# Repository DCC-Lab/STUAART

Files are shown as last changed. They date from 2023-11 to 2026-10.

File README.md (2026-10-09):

# STUAART

Repository of the STUAART project. 
Authors of this README : Valérie Pineau Noël, Nathan Bérubé and Daniel C. Côté (DCC/M-lab, CERVO brain research center, Université Laval)

## Overview

STUAART is an automated weighing system for mice that tracks individual weights over weeks. Each cage holds three independent scales ; each scale is a load cell (Wheatstone bridge) read by an HX711 24-bit amplifier connected via a 2-pin protocol (DOUT, SCK) to a DFRobot FireBeetle ESP32 V1 microcontroller. The microcontroller logs every measurement to a microSD card and exposes a small HTTP server so a host can pull today's CSV over Wi-Fi.

## Repository layout

| Folder | What's there |
|---|---|
| `Arduino/` | Custom libraries and scripts to run the STUAART. |
| `KiCAD/` | PCB schematic and design mde on KiCAD (version 10.0.7). |
| `CAD/` | Mechanical 3D files for the scale platforms. Print the top platform with high infill density to keep stiffness and reduce creep. |
| `FlaskServer/` | Python script used to catch the data and save on a local NAS. |
| `Notebooks/` | Notebooks that users can run in Google Colaboratory for data post-processing. |

## Getting started with the firmware

1. Install Arduino IDE 2.x or `arduino-cli`.
2. Add the Espressif boards URL in Preferences and install the `esp32` core (board package). 
3. Copy and save files in folder `Arduino` on your computer. 
4. Copy and save the Python script in `FlaskServer` in your local NAS and run it. 
5. If you are using a new Firebeetle ESP-32 board, run `Arduino/FormatSPIFFS/FormatSPIFFS.ino` (prevent error `SPIFFS Mount Failed`). Otherwise, go to the next step. 
6. Open `Arduino/STUAART/STUAART.ino`.
7. Download third-party libraries in the Arduino IDE. See section *Required third-party libraries*.
8. In the Arduino IDE, pick board `FireBeetle-ESP32` (`esp32:esp32:firebeetle32`) in  Tools -> Port, pick the USB serial port, then Verify and Upload.

## Required third-party libraries

Install these via Arduino IDE Library Manager (Sketch -> Include Library -> Manage Libraries):

| Library | Author | Tested version |
|---|---|---|
| HX711 | Bogdan Necula (bogde) | 0.7.5 |
| RTClib | Adafruit | 2.1.4 |
| ArduinoJson | Benoit Blanchon | 7.0.4 |

## A minimal load cell read

```cpp
#include "LoadCell.h"
#include "LoadCellController.h"

LoadCell loadcell;
LoadCellController controller;

void setup() {
  Serial.begin(115200);
  controller.add_loadcell(loadcell);
  controller.easy_start_with_params(
      1,        // loadcell number
      27,       // DOUT pin (avoid GPIO 6-11, those are the flash bus)
      17,       // SCK pin
      true,     // calibrate offset
      true,     // calibrate scale
      false,    // read offset from memory
      false,    // read scale from memory
      true,     // save offset to memory
      true,     // save scale to memory
      0,        // manual tare offset (0 = not specified)
      0,        // manual scale coeff (0 = not specified)
      128       // gain, do not change
  );
}

void loop() {
  controller.wait_ready_timeout(1, 1000);
  float reading = controller.get_weight(1);
  Serial.println(reading);
}
```

## Mass time series analysis

Each step of the post-processing analysis can be performed using notebooks run via Google Colaboratory. To begin, the raw mass time series must be uploaded to the user's personal Google Drive. We also recommend that users save a personal copy of each notebook to their own Google Drive by clicking on *File > Save a copy in Drive* once opened via the links below. Users are free to modify their own versions of the notebooks as desired. 

1. **Remove buffer flush indicators from the raw mass time series** : String such as "--, --, --, -- \n" are saved in the raw data to indicate the moments when the buffer flushed its contents onto the SD card. This data can be used to evaluate the time it takes to flush all data and how many times the buffer flushes the data over a given period. For further analysis, these indicators nust be removed. You can do this using this notebook :


2. **Correct for baseline shift and remove outliers** : This step is the most computationally intensive. Longitudinal mass time series are affected by mechanical and thermal drifts that alter the value of the initial tare and shift the measured mass by multiple grams, which must be corrected to ensure accuracte evaluation. Additionally, transient spikes can occur and should be filtered out. Users can choose whether to remove outliers and select which baseline correction algorithm best suits their data. Four baseline correction algorithms are provided : density-based spatial clustering of applications with noise (DBSCAN), kernel-density estimation (KDE), Gaussian mixture model (GMM) and a custom rolling-mean filtering. As presented in the main manuscript, the authors achieved optimal results with DBSCAN, while the custom rolling-mean filtering performs well for more stable data sets. We also provide a graphical user interface (GUI) for manual baseline fine-tuning and quick data visualization. We suggest testing different algorithms and using the notebook *Compute_metrics.ipnyb* to evaluate quantitatively the accuracy and precision of the baseline-corrected mass compared to ground-truth mass measurements. If ground-truth data was not acquired, a simple visual inspection of the baseline-corrected mass time series can guide algorithm selection. More information is available in the supplementary information document and within the notebook :


3. **Display mass time series and compute mass per time bin** : After baseline correction and outlier removal, the users can display the mass time series for visual evaluation. The data can be displayed per scale, for the overall measured mass of the system (summed mass time series per timepoint) and by the relative mass change (where the mass at time = 0 hour is 0%). The users can also obtain the mass per time bin. 


4. **Compute metrics** : Quantitative evaluation of the mass compared to ground-truth measurements can be obtained via this notebook : 


5. **Evaluate location, grid-hanging and active state behaviors** : Three additional notebooks are provided to identify and evaluate the spatial occupancy of each scale, the grid-hanging behavior and the active VS inactive states over time. 
   - 
   - 
   - 

## Error management 

- `Unable to verify flash chip connection` : the default upload speed of 921600 baud is too fast for the CH340 USB-serial chip on the FireBeetle. Set 115200. 

- `SPIFFS Mount Failed` : Run the script in `Arduino/FormatSPIFFS/FormatSPIFFS.ino`. 

- The "GPIO 9 = flash" issue on cell 1 is the root cause of corrupted readings (raw == 0xFFFFFF returned as -160.68 g). A defensive software patch in `LoadCell.cpp` rejects this signature, but the long-term fix is to reroute that DOUT to GPIO 25 or 26 (silkscreen D2 or D3).

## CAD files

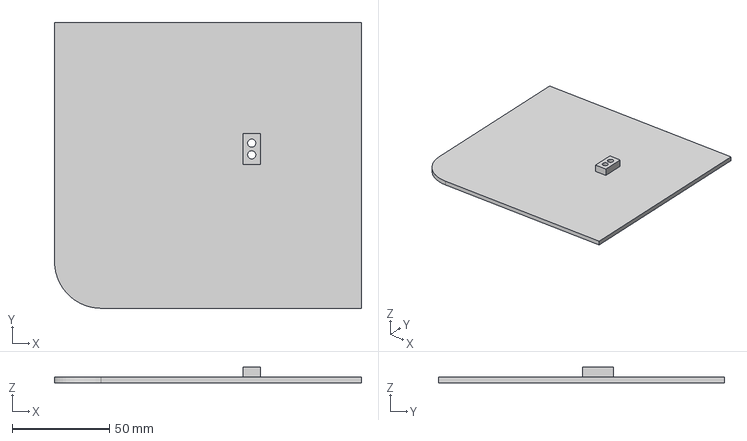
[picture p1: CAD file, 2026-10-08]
CAD/TopRight.step
158.0 x 147.0 x 8.00 mm

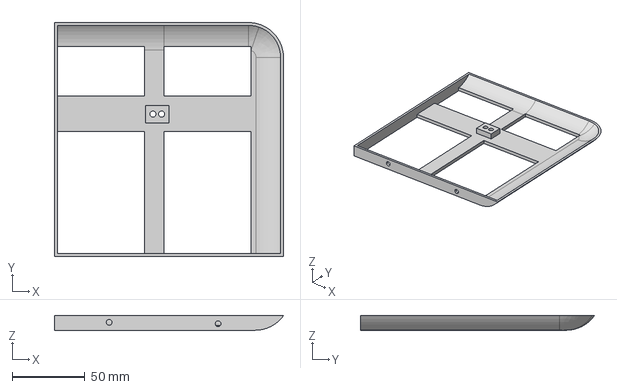
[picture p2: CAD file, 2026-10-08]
CAD/BottomRight.step
157.6 x 161.0 x 10.0 mm

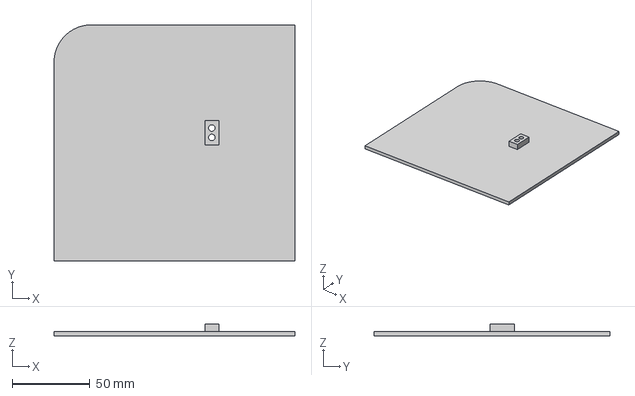
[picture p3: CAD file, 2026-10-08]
CAD/TopLeft.step
155.0 x 152.0 x 8.00 mm

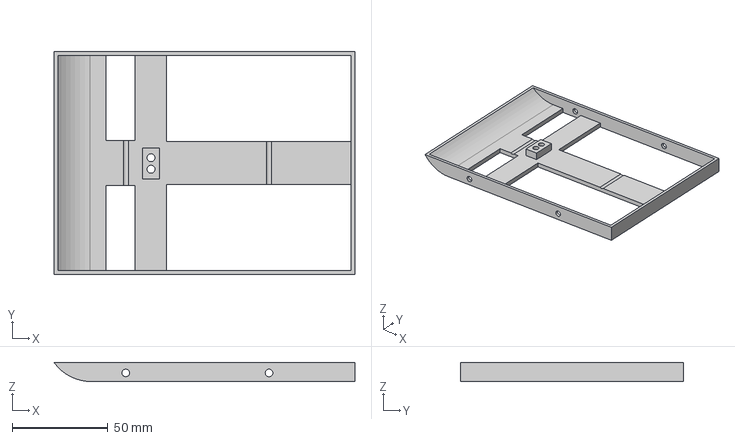
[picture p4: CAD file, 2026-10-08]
CAD/BottomMiddle.step
157.6 x 116.5 x 10.0 mm

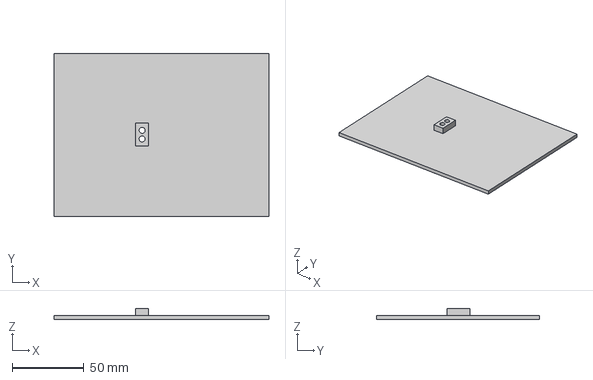
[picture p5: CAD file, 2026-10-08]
CAD/TopMiddle.step
150.0 x 114.0 x 8.00 mm

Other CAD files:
CAD/BottomLeft.step

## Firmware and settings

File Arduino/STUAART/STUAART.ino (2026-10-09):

#include "LoadCell.h"
#include "LoadCellController.h"
#include <WiFi.h>
#include <SD.h>
#include <SPI.h>
#include <Wire.h>
#include "RTClib.h"
#include <time.h>
#include <HTTPClient.h>
#include <ArduinoJson.h>  // Install via Library Manager
#include <esp_system.h>

RTC_PCF8523 rtc; // Create an RTC object for the PCF8523

LoadCell loadCell1;
LoadCell loadCell2;
LoadCell loadCell3;
LoadCellController controller;

const int pinLED1 = 10;
const int pinLED2 = 2;
const int pinLED3 = 14;
const int pinLED4 = 15;

const int MODE_PIN = 13; //Switch pin allowing to put in setup mode.

File myFile;           // initialize the file
const int SS_PIN = 5; // seule pin de carte SD à spécifier

// Compiled-in defaults. Overridden at boot by /wifi.txt on SPIFFS if
// present. Use the `wifi set <ssid> <password>` serial command to
// change them at runtime ; the new values are persisted to SPIFFS so
// they survive reboots.
char ssid[64]     = "INTERNET-EQUIPEMENTS";
char password[64] = "zfrnxbg7";
WiFiServer server(80);             // créer un serveur qui écoute les clients qui veulent s'y connecter

const char *REFRESH_CODE = "refresh"; // must be the same as in the python code, otherwise they won't be able to recognize one another

unsigned long saveTimestamp = 0;
const int SAVE_DATA_INTERVAL = 0; 

unsigned long reconnectTimestamp = 0;
const int RECONNECT_WIFI_INTERVAL = 3600000;
const unsigned long WIFI_CONNECT_TIMEOUT_MS = 15000;
bool wifiConnected = false;
bool sdInitialized = false;
bool webServerStarted = false;     // set when server.begin() succeeds
bool streamOn = false;                  // CSV stream to Serial : OFF by default
const size_t CMD_BUF_SIZE = 64;
char cmdBuf[CMD_BUF_SIZE];              // accumulates one line of user input
size_t cmdLen = 0;
char pendingCmd[CMD_BUF_SIZE] = "";     // command awaiting y/n confirmation

// Ring buffer of the last BUFFER_SIZE CSV lines, kept in RAM
// independently of the SD card. The ring overwrites the oldest line
// when full, so it always reflects the most recent ~12 s of data
// (1000 samples / 80 Hz). Used both for batched SD writes and to back
// the HTTP `/recent` endpoint.
const int BUFFER_SIZE = 1000;
const int LINE_LENGTH = 64;        // max line for 7-column 7-field CSV
char buffer[BUFFER_SIZE][LINE_LENGTH];
int  head = 0;                     // next slot to write
int  tail = 0;                     // oldest slot (== head when full)
bool bufferFull = false;
unsigned long ringWrites    = 0;   // total adds since boot
unsigned long ringSdFlushed = 0;   // number of writes already on SD
const int SD_FLUSH_EVERY = 500;    // flush every ~6 s at 80 Hz

//Buffer chars for saving files
static char today[16];
static char yesterday[16];

char currentTime[13];

/**
 * @brief Try to connect to WiFi using the hardcoded SSID and PASSWORD.
 *
 * Retries every 500 ms until the chip reports `WL_CONNECTED` or the
 * configured `WIFI_CONNECT_TIMEOUT_MS` (15 s) elapses, whichever comes
 * first. On success, sets the global `wifiConnected = true`, starts the
 * HTTP `server`, and blinks `pinLED2` three times. On timeout, sets
 * `wifiConnected = false` and continues without network ; the firmware
 * keeps logging to SD and (if enabled) Serial.
 *
 * Called once from @ref setup and again on a 1-hour interval from
 * @ref loop, so a transient outage recovers automatically.
 */
void logResetReasonToSD() {
  esp_reset_reason_t reason = esp_reset_reason();
  String reasonStr = "";

  // Translate the ESP32 hardware flag into a clear text message
  switch (reason) {
    case ESP_RST_POWERON:  reasonStr = "POWER-ON (Normal cold boot)"; break;
    case ESP_RST_BROWNOUT: reasonStr = "BROWNOUT DETECTED! (Voltage dipped too low)"; break;
    case ESP_RST_SW:       reasonStr = "SOFTWARE RESET (Rebooted via code)"; break;
    case ESP_RST_PANIC:    reasonStr = "CRASH / PANIC (Exception or code error)"; break;
    case ESP_RST_INT_WDT:  reasonStr = "WATCHDOG TIMEOUT (Interrupt WDT)"; break;
    case ESP_RST_TASK_WDT: reasonStr = "WATCHDOG TIMEOUT (Task WDT)"; break;
    case ESP_RST_DEEPSLEEP:reasonStr = "DEEP SLEEP WAKEUP"; break;
    case ESP_RST_EXT:      reasonStr = "EXTERNAL RESET (Reset button pressed)"; break;
    default:               reasonStr = "UNKNOWN RESET REASON"; break;
  }

  // Open a system log file on the SD card (or append to your main CSV)
  File logFile = SD.open("/system_log.txt", FILE_APPEND);
  if (logFile) {
    logFile.print("[BOOT EVENT] Reason: ");
    logFile.println(reasonStr);
    logFile.close();
  }
}


void connectToWifi()
{
  // Disconnect any previous attempt and clear the AP config so a fresh
  // begin() does not collide with an in-flight state machine. Without
  // this, calling connectToWifi a second time (e.g. after a `wifi set`
  // command) triggers ESP-IDF :
  //     E (xxxxx) wifi:sta is connecting, cannot set config
  // even though the previous attempt has already timed out.
  WiFi.disconnect(false, true);   // (wifioff=false, eraseap=true)
  WiFi.mode(WIFI_STA);
  delay(100);

  Serial.print("Connecting to ");
  Serial.println(ssid);
  WiFi.begin(ssid, password);
  unsigned long start = millis();
  while (WiFi.status() != WL_CONNECTED && (millis() - start) < WIFI_CONNECT_TIMEOUT_MS)
  {
    delay(500);
    Serial.print(".");
  }
  Serial.println("");
  if (WiFi.status() == WL_CONNECTED) {
    wifiConnected = true;
    Serial.println("WiFi connected.");
    Serial.println("IP address: ");
    Serial.println(WiFi.localIP());
    server.begin();
    webServerStarted = true;
    for (int i = 0; i < 3; i++) {
      digitalWrite(pinLED2, HIGH); delay(100);
      digitalWrite(pinLED2, LOW);  delay(100);
    }
  } else {
    wifiConnected = false;
    Serial.println("WiFi unavailable, continuing without network.");
  }
}


/**
 * @brief Load WiFi credentials from `/wifi.txt` on SPIFFS into the
 * global `ssid` and `password` buffers.
 *
 * File format : two lines, SSID then PASSWORD, each terminated by a
 * newline. If the file is absent, malformed, or SPIFFS itself fails
 * to mount, the compiled-in defaults are kept untouched. Called once
 * from setup() before the first connectToWifi() attempt.
 */
void loadWifiConfig() {
  if (!SPIFFS.begin(true)) return;
  File f = SPIFFS.open("/wifi.txt", FILE_READ);
  if (!f) return;
  String s = f.readStringUntil('\n'); s.trim();
  String p = f.readStringUntil('\n'); p.trim();
  f.close();
  if (s.length() > 0 && s.length() < sizeof(ssid))     strcpy(ssid, s.c_str());
  if (p.length() > 0 && p.length() < sizeof(password)) strcpy(password, p.c_str());
  Serial.print(F("Loaded WiFi SSID from SPIFFS: "));
  Serial.println(ssid);
}

/**
 * @brief Persist the current `ssid` and `password` buffers to
 * `/wifi.txt` on SPIFFS so they survive a reboot.
 *
 * @return true if the file was written successfully.
 */
bool saveWifiConfig() {
  if (!SPIFFS.begin(true)) return false;
  File f = SPIFFS.open("/wifi.txt", FILE_WRITE);
  if (!f) return false;
  f.println(ssid);
  f.println(password);
  f.close();
  return true;
}

/**
 * @brief Print the current WiFi SSID on Serial. The password is NEVER
 * printed (anyone with access to the bench Serial port could read it).
 */
void printWifiConfig() {
  Serial.print(F("SSID     : ")); Serial.println(ssid);
  Serial.print(F("password : (not shown ; "));
  Serial.print(strlen(password));
  Serial.println(F(" chars stored)"));
  Serial.print(F("connected: "));
  Serial.println(wifiConnected ? "yes" : "no");
}

/**
 * @brief Fetch the current local time from timeapi.io over HTTPS.
 *
 * Issues a GET to `https://timeapi.io/api/Time/current/zone?timeZone=America/Toronto`,
 * parses the JSON response with ArduinoJson, and reads the `datetime`
 * field. Currently the result is not pushed to the RTC (the JSON is
 * extracted but the assignment is commented out) ; this function is a
 * stub for future synchronization.
 *
 * Requires WiFi to be connected. Logs an error otherwise.
 */
void getTimeHTTP() {
  if ((WiFi.status() == WL_CONNECTED)) {
    HTTPClient http;
    // Make request to worldtimeapi.org for your timezone (or "api/ip" for auto-detect)
    http.begin("https://timeapi.io/api/Time/current/zone?timeZone=America/Toronto");
    int httpCode = http.GET();

    if (httpCode > 0) { // Check for the returning code
      String payload = http.getString();
      // Serial.println("HTTP Response:");
      // Serial.println(payload);
      // Parse JSON
      DynamicJsonDocument doc(4096);
      DeserializationError error = deserializeJson(doc, payload);
      if (!error) {
        const char* datetime;
        datetime = doc["datetime"];  // e.g., "2025-10-02T17:15:30.123456+00:00"
        // Serial.print("Current time: ");
        // Serial.println(datetime);
      } else {
        Serial.print("JSON parse error: ");
        Serial.println(error.c_str());
      }
    } else {
      Serial.print("HTTP GET failed, code: ");
      Serial.println(httpCode);
    }
    http.end();
  } else {
    Serial.println("WiFi not connected");
  }
}



/**
 * @brief Initialize the PCF8523 real-time clock and seed it with the
 * compile-time date and time.
 *
 * Halts the firmware in an infinite loop if `rtc.begin()` fails (no
 * RTC found on the I2C bus). On success, calls `rtc.adjust()` with
 * the `__DATE__`/`__TIME__` macros so the clock is at least roughly
 * correct after a flash, and `rtc.start()` to clear any STOP bit.
 *
 * The compile-time seed is a coarse fallback ; for accurate time use
 * the `time YYYY-MM-DD HH:MM:SS` serial command after boot.
 */
void startRealTimeClock(){
  // Wait for serial port to connect. Needed for native USB port only
  #ifndef ESP8266
    while (!Serial); 
  #endif
  if (! rtc.begin()) { // Attempt to initialize the RTC
    Serial.println("Couldn't find RTC");
    Serial.flush();
    while (1) delay(10);
  }

  else {
    Serial.println("RTC setup succeeded");
  }
  if (digitalRead(MODE_PIN) == HIGH) { // during manual calibration mode
    rtc.adjust(DateTime(F(__DATE__), F(__TIME__))); 
  }
  rtc.start(); // Ensure the RTC is running (clears the STOP bit if necessary)
}


/**
 * @brief Format today's date as a CSV filename in the global `today[]`
 * buffer, e.g. `/2026.05.06.csv`.
 *
 * Reads the current time from the PCF8523 RTC and writes the formatted
 * string into `today[]` via `snprintf`. Used by @ref saveData to pick
 * the destination file on the SD card.
 */
void getTodaysDate(){
  DateTime now = rtc.now(); // Get the current date and time from the RTC
  int year = now.year();
  int month = now.month();
  int day = now.day();

  snprintf(today, sizeof(today), "/%04d.%02d.%02d.csv", year, month, day);
} 


/**
 * @brief Format yesterday's date as a CSV filename in the global
 * `today[]` buffer (sic ; the function reuses the same buffer).
 *
 * @warning Naive implementation : subtracts 1 from `now.day()` without
 * handling month / year roll-over. Fails on the first of any month.
 */
void getYesterdaysDate(){
  DateTime now = rtc.now(); // Get the current date and time from the RTC
  int year = now.year();
  int month = now.month();
  int day = now.day() - 1;

  snprintf(today, sizeof(today), "/%04d.%02d.%02d.csv", year, month, day);
}


/*
Gets current time from the real-time clock.
*/
void getCurrentTime(){
  DateTime now = rtc.now(); // Get current date and time from the RTC
  int hours = now.hour();
  int minutes = now.minute();
  int seconds = now.second();

  int milliseconds = millis() % 1000;

  snprintf(currentTime, sizeof(currentTime), "%02d:%02d:%02d.%03d", hours, minutes, seconds, milliseconds);
}


/*
Writes a file in the SD card at the specified path. Puts in the specified message.
Writes in the serial consol error if it doesn't succeed.
*/
void writeFile(const char *path, const char *message, const char *mode){
  if (bufferFull == false){
    addToBuffer(message);
  }
  else
    {
      while (!Serial)
    {
      ; // wait for serial port to connect. Needed for native USB port only
    }
      // open the file. note that only one file can be open at a time,
    myFile = SD.open(path, mode);
    // if the file opened okay, write to it:
    if (myFile)
      {
      // close the file:
      flushBufferToSD();
      myFile.print(message);
      myFile.close();
      digitalWrite(pinLED1, HIGH);
      delay(50);
      digitalWrite(pinLED1, LOW);
      }
    else
      {
      // if the file didn't open, print an error:
      Serial.println("error opening file");
      }
}
}

/**
 * @brief Create or truncate a file on the SD card and write a single
 * line to it.
 *
 * Used by @ref writeFileHeader to drop the CSV header at the top of a
 * new daily file. No-op if `sdInitialized` is `false`.
 *
 * @param path Destination filename on the SD card.
 * @param message Null-terminated text written via `myFile.println()`
 * (a `\n` is appended automatically).
 * @param mode Typically `FILE_WRITE` (truncates).
 */
void createFile(const char *path, const char *message, const char *mode){
  if (!sdInitialized) return;
  myFile = SD.open(path, mode);
  if (myFile) {
    myFile.println(message);
    myFile.close();
  } else {
    Serial.println("error opening file");
  }
}


/**
 * @brief Append a CSV line to the in-RAM ring buffer with overwrite-oldest
 * semantics.
 *
 * Copies up to `LINE_LENGTH - 1` characters from `message` into
 * `buffer[head]`, advances head modulo BUFFER_SIZE, and once the ring
 * is full keeps `tail` glued to head so the oldest line is dropped on
 * each new write. The ring therefore always reflects the most recent
 * BUFFER_SIZE samples regardless of SD availability.
 *
 * @param message Null-terminated CSV line (truncated if longer than
 * `LINE_LENGTH - 1` bytes).
 */
void addToBuffer(const char *message) {
  strncpy(buffer[head], message, LINE_LENGTH - 1);
  buffer[head][LINE_LENGTH - 1] = '\0';
  head = (head + 1) % BUFFER_SIZE;
  if (bufferFull) {
    tail = (tail + 1) % BUFFER_SIZE;     // drop oldest
  } else if (head == tail) {
    bufferFull = true;                   // first wrap : ring is now full
  }
  ringWrites++;
}


/**
 * @brief Stream the ring buffer contents (oldest to newest) to a Print
 * target.
 *
 * Used both for SD flushing and for the HTTP `/recent` endpoint. The
 * ring itself is unchanged after the call : the data remains available
 * for further consumers.
 *
 * @param out Print target (File, WiFiClient, HardwareSerial, etc.).
 */
void streamRingTo(Print &out) {
  int n     = bufferFull ? BUFFER_SIZE : head;
  int start = bufferFull ? head : 0;     // when not full, oldest is slot 0
  for (int i = 0; i < n; i++) {
    out.print(buffer[(start + i) % BUFFER_SIZE]);
  }
}


void flushBufferToSD(){
  while (head != tail || bufferFull) {
    myFile.print(buffer[tail]);
    tail = (tail + 1) % BUFFER_SIZE;
    bufferFull = false;
  }
  myFile.print("--, --, --, -- \n");
}



/**
 * @brief Write the 7-column CSV header at the top of a new daily file.
 *
 * Header :
 * `time (ms), reading 1, reading 2, reading 3, raw 1, raw 2, raw 3`
 *
 * The `reading` wording is preserved so existing post-processing scripts
 * that match on those names keep working ; the three `raw` columns are
 * the new signed 24-bit HX711 counts.
 *
 * @param file_name Destination CSV path on the SD card.
 */
void writeFileHeader(char *file_name) {
  createFile(file_name, "time [HH:MM:SS.MS], reading 1, reading 2, reading 3", FILE_WRITE);
}


/**
 * @brief Sample the 3 load cells once and persist the row.
 *
 * Reads the raw 24-bit count from each cell via `read_raw_average()`
 * and converts each one to grams via `mass_from_raw()`, so the weight
 * and raw on the same line come from the *same* HX711 conversion (no
 * double read). Builds a 7-field CSV line :
 *
 * `time(ms), w1, w2, w3, raw1, raw2, raw3\n`
 *
 * If the SD card is initialised, the line is appended to today's file
 * (creating it with a header if needed). If `streamOn` is true, the
 * same line is mirrored on Serial.
 *
 * Called every iteration of @ref loop ; throughput is bounded by the
 * HX711 conversion rate (~80 Hz on STUAART hardware).
 */
void saveData()
{
  // Read raws once and derive weights from them, so the two values on
  // the same line come from the SAME HX711 conversion (no double read).
  long raw1 = controller.read_raw_average(1);
  long raw2 = controller.read_raw_average(2);
  long raw3 = controller.read_raw_average(3);
  float weight1 = controller.mass_from_raw(1, raw1);
  float weight2 = controller.mass_from_raw(2, raw2);
  float weight3 = controller.mass_from_raw(3, raw3);

  getCurrentTime();

  String fileLine = "";
  fileLine += String(currentTime) + "," + weight1 + "," + weight2 + "," + weight3 + "\n";

  // Always feed the ring : it backs the HTTP /recent endpoint and the
  // SD flush below. Independent of sdInitialized.
  addToBuffer(fileLine.c_str());

  // Periodic SD flush : every SD_FLUSH_EVERY samples, append the most
  // recent unflushed lines to today's file. Doing it in batches avoids
  // opening / closing SD on every sample.
  if (sdInitialized && (ringWrites - ringSdFlushed) >= (unsigned long) SD_FLUSH_EVERY) {
    getTodaysDate();
    if (!SD.exists(today)) writeFileHeader(today);

    myFile = SD.open(today, FILE_APPEND);
    if (myFile) {
      int toWrite = (int) (ringWrites - ringSdFlushed);
      if (toWrite > BUFFER_SIZE) toWrite = BUFFER_SIZE;   // cap to ring depth
      int start = (head - toWrite + BUFFER_SIZE) % BUFFER_SIZE;
      for (int i = 0; i < toWrite; i++) {
        myFile.print(buffer[(start + i) % BUFFER_SIZE]);
      }
      myFile.close();
      ringSdFlushed = ringWrites;
      digitalWrite(pinLED1, HIGH); delay(100); digitalWrite(pinLED1, LOW);
    } else {
      Serial.println(F("SD append failed (will retry on next flush)"));
    }
  }

  if (streamOn) {
    Serial.print(fileLine);
  }
}
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
void loop() {
  unsigned long currentMillis = millis();

  // Serial command interface
  processSerialInput();

  // Save data on SD card
  if (abs((long)(currentMillis - saveTimestamp)) >= SAVE_DATA_INTERVAL) {
    saveTimestamp = currentMillis;
    saveData();
  }

  // Reconnect WiFi is disconnected 
  if (abs((long)(currentMillis - reconnectTimestamp)) >= RECONNECT_WIFI_INTERVAL) {
    reconnectTimestamp = currentMillis;
    connectToWifi();
  }

  if (millis() - lastUploadTime > 300000) {
    getTodaysDate();
    pushToServer(today);
    lastUploadTime = millis();
  }
}

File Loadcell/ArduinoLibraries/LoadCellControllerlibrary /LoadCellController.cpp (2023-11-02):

#include "LoadCellController.h"

LoadCellController::LoadCellController()
{
}

void LoadCellController::add_loadcell(LoadCell &loadcell)
{
    loadcells[n_loadcell] = &loadcell;
    n_loadcell++;
}

void LoadCellController::easy_start_with_params(
    byte loadcell_num,
    byte dout,
    byte pd_sck,
    bool calibrate_offset,
    bool calibrate_scale,
    bool read_offset_persistent_memory,
    bool read_scale_persistent_memory,
    bool save_offset_persistent_memory,
    bool save_scale_persistent_memory,
    float tare_offset,
    float scale_coeff,
    byte gain)
    {
    easy_handle_exceptions(
        loadcell_num,
        calibrate_offset,
        calibrate_scale,
        read_offset_persistent_memory,
        read_scale_persistent_memory,
        save_offset_persistent_memory,
        save_scale_persistent_memory,
        tare_offset,
        scale_coeff);

    LoadCell *loadcell_ptr = loadcells[loadcell_num - 1];

    loadcell_ptr->begin(dout, pd_sck, gain);

    loadcell_ptr->set_offset(tare_offset);
    loadcell_ptr->set_scale(scale_coeff);

    easy_read_from_persistent_memory_with_params(
        loadcell_num,
        read_offset_persistent_memory,
        read_scale_persistent_memory);

    easy_calibration_with_params(
        loadcell_num,
        calibrate_offset,
        calibrate_scale); // set offset and scale with calibration or with value

    easy_save_to_persistent_memory_with_params(
        loadcell_num,
        save_offset_persistent_memory,
        save_scale_persistent_memory); // set offset and scale with calibration or with value
    Serial.println(F("---------***---------"));
}

void LoadCellController::easy_read_from_persistent_memory_with_params(
    byte loadcell_num,
    bool read_offset,
    bool read_scale)
{
    LoadCell *loadcell_ptr = loadcells[loadcell_num - 1];

    if (read_offset && read_scale)
    {
        loadcell_ptr->set_offset(read_offset_from_persistent_memory(loadcell_num));
        loadcell_ptr->set_scale(read_scale_coeff_from_persistent_memory(loadcell_num));
        Serial.println(F("Offset and scale coefficient read from memory"));
        Serial.print(F("Offset: "));
        Serial.println(loadcell_ptr->get_offset());
        Serial.print(F("Scale coefficient: "));
        Serial.println(loadcell_ptr->get_scale());
        Serial.println(F("---------***---------"));
    }
    else if (read_offset && !read_scale)
    {
        loadcell_ptr->set_offset(read_offset_from_persistent_memory(loadcell_num));
        Serial.println(F("---------***---------"));
        Serial.println(F("Offset read from memory"));
        Serial.print(F("Offset: "));
        Serial.println(loadcell_ptr->get_offset());
    }
    else if (!read_offset && read_scale)
    {
        loadcell_ptr->set_scale(read_scale_coeff_from_persistent_memory(loadcell_num));
        Serial.println(F("---------***---------"));
        Serial.println(F("Scale coefficient read from memory"));
        Serial.print(F("Scale coefficient: "));
        Serial.println(loadcell_ptr->get_scale());
    }
}

void LoadCellController::easy_calibration_with_params(
    byte loadcell_num,
    bool calibrate_offset,
    bool calibrate_scale)
{
    LoadCell *loadcell_ptr = loadcells[loadcell_num - 1];
    if (calibrate_offset && calibrate_scale)
    {
        calibrate_both_params(loadcell_num); // set offset and scale
        Serial.print(F("Offset: "));
        Serial.println(loadcell_ptr->get_offset());
        Serial.print(F("Scale coefficient: "));
        Serial.println(loadcell_ptr->get_scale());
    }
    else if (calibrate_offset && !calibrate_scale)
    {
        calibrate_tare_offset(loadcell_num); // set offset
    }
    else if (!calibrate_offset && calibrate_scale)
    {
        calibrate_scale_coeff(loadcell_num); // set scale
    }
}

void LoadCellController::easy_save_to_persistent_memory_with_params(
    byte loadcell_num,
    bool save_offset,
    bool save_scale)
{
    LoadCell *loadcell_ptr = loadcells[loadcell_num - 1];

    if (save_offset && save_scale)
    {
        save_offset_to_persistent_memory(loadcell_num);
        save_scale_coeff_to_persistent_memory(loadcell_num);
        Serial.println(F("---------***---------"));
        Serial.println(F("Offset and scale coefficient saved to persistent memory."));
        Serial.print(F("Offset: "));
        Serial.println(loadcell_ptr->get_offset());
        Serial.print(F("Scale coefficient: "));
        Serial.println(loadcell_ptr->get_scale());
    }
    else if (save_offset && !save_scale)
    {
        save_offset_to_persistent_memory(loadcell_num);
        Serial.println(F("---------***---------"));
        Serial.println(F("Offset saved to persistent memory."));
        Serial.print(F("Offset: "));
        Serial.println(loadcell_ptr->get_offset());
    }
    else if (!save_offset && save_scale)
    {
        save_scale_coeff_to_persistent_memory(loadcell_num);
        Serial.println(F("---------***---------"));
        Serial.println(F("Scale coefficient saved to persistent memory."));
        Serial.print(F("Scale coefficient: "));
        Serial.println(loadcell_ptr->get_scale());
    }
}

void LoadCellController::easy_start_with_questions(
    byte loadcell_num,
    byte dout,
    byte pd_sck,
    byte gain)
{
    // not implemented
}
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

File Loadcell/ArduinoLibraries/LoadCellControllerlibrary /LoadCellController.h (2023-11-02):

/**
 * @file LoadCellController.h
 *
 * @class LoadCellController
 * @brief  This library allows to control and manage many load cells with a LoadCellController
 *
 * The LoadCellController library offers many features:
 *
 * - Calibrate load cells, both parameters (offset and scale coefficient)
 *
 *      - Member functions encapsulate the scripts needed for the calibration
 *      for both parameters. The interaction with the user is done inside the
 *      member functions.
 *
 * - Save the calibration parameters to persistent memory (tested on Arduino Uno August 2023)
 *      
 *      The library can automatically detect if an Arduino Uno (ATmega328p chip) or a FireBeetle
 *      (ESP8266) is used. For Arduino Uno, EEPROM is used to store calibration parameters.
 *      For FireBeetle, SPIFFS is used.
 *
 *      The calibration parameters can be saved on the EEPROM after calibration for
 *      Atmega328p chip (Arduino Uno). These types of persistent memory are useful 
 *      when it comes to saving because the saved values don't erase themselves when the
 *      power supply of the microcontroller is cut. The saved parameters can
 *      be reused at another moment. (tested on Arduino Uno and FireBeetle November 2023)
 *
 * - Read the calibration parameters from persistent memory (tested on Arduino Uno August 2023)
 *
 *      - The calibration parameters can also be read from peristent memory after being saved.
 *
 * - "Easy" start-up function that will handle everything related to the calibration and manage
 *        the calibration parameters.
 *
 *      - The LoadCellController class offers ready-to-use "easy" functions that simplify the
 *      start-up of a load cell. Many scenarios are possible for the start-up of a load cell when
 *      it comes to calibration and the management of the calibration parameters. 
 *
 *      - A simple function @ref easy_start_with_params() takes in arguments many parameters to
 *      choose the appropriate option. Only a few parameters are needed.
 *              
 *      - This is useful for those who don't want to create their own sketch.
 *
 *      - All the member functions that begin with "easy" are for easy start-up and don't implement any other 
 *      functionalities than the other member functions. They only offer a "all-in-one" option for those
 *      who don't want to code.
 *
 * - The LoadCellController class allows to access the load cells through the controller.
 *
 *      The load cells are added with the member function @ref add_loadcell(). After that, all load cells are under
 *      the control of the LoadCellController and the member functions of the LoadCell class are accesed through
 *      the controller.
 *              
 *      This access to the LoadCells through the LoadCellController requires to specify to LoadCellController
 *      a parameter corresponding to the number identifying the LoadCell concerned (1, 2, ...). Every member
 *      functions that have as input the number of a LoadCell (n_loadcell) will verify if the LoadCell number
 *      is in a coherent range according to the number of LoadCells added to the controller according to the
 *      member variable @ref n_loadcell. If the value is out of the range, the code will be suspended with a
 *      endless while() loop and display on the serial monitor an error message specifying where the problem
 *      occured (in which function). This small if bloc is placed at the beginning
 *      @code
 *      if (is_loadcell_num_in_range(loadcell_num) == false) {
        Serial.println();
        Serial.println();
        Serial.println();
        Serial.print(F("ERROR 1 name_of_the_function(): loadcell number "));
        Serial.print(loadcell_num);
        Serial.println(F(" is out of range."));
        while(1);
        }
 *      @endcode
 *
 * HX711 library: https://github.com/bogde/HX711
 * 
 * LoadCell library: https://github.com/DCC-Lab/IntelligentCage/tree/master/Loadcell/Arduino%20libraries/LoadCellLibrary
 * @author Nathan Bérubé
 * @date November 1st, 2023
 * @version 2.0.0
 */
#ifndef LoadCellController_h
#define LoadCellController_h
#include <Arduino.h>
#include "HX711.h"
#include "LoadCell.h"

// Verify if the board is based on a ESP32 chip, like FireBeetle
#if defined(ARDUINO_ARCH_ESP32)
#include "FS.h"
#include "SPIFFS.h"
// Verify if the board is based on a Atmega328P chip, like Arduino Uno
#elif defined(__AVR_ATmega328P__)
#include <EEPROM.h>
#endif


class LoadCellController {
protected:
        /**
        * @var Loadcell* loadcells
        * @brief Array containing the pointer of the LoadCell controlled by the LoadCellController.
        * 
        * The only moment this variable is modified is  when a LoadCell is added with the
        * @ref add_loadcell() member function. It goes up by one every time @ref add_loadcell()
        * is called.
        */
        LoadCell* loadcells[10];


        /**
        * @var int n_loadcell
        * @brief Member variable used to keep track of the number of LoadCells added.
        * 
        * The only moment this variable is modified is  when a LoadCell is added with the
        * @ref add_loadcell() member function. It goes up by one every time @ref add_loadcell()
        * is called.
        */
        int n_loadcell = 0;

        /**
        * @brief Easy function managing the calibration of a LoadCell.
        *
        * This function is managing the possibilities that come with the calibration of 
        * the tare offset and the scale coefficient. It is meant to be used inside the member
        * function @ref easy_start_with_params(). 
        * 
        * The calibration process of both parameters (offset and scale coefficient) requires a computer
        * to display information on the serial monitor and also to send value through it for the calibration.
        * 
        * @param loadcell_num Number of the LoadCell.
        * @param cal_tare Boolean telling if the offset should be calibrated.
        * @param save_scale Boolean telling if the scale coefficient should be calibrated.
        */
        void easy_calibration_with_params(
                                        byte loadcell_num,
                                        bool cal_tare,
                                        bool cal_scale
                                        );
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

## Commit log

2023-07-13 Add drift data and drift arduino code
    Add drift data and drift arduino code used in all drift tests
    [2023-06-14.CSV, 2023-06-15.CSV, 2023-06-16.CSV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]
2023-07-17 Change in files organisation
    [2023-06-14.CSV, 2023-06-15.CSV, 2023-06-16.CSV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]
2023-07-17 Revert "Change in files organisation"
    This reverts commit 7d40114fee22f022c0227356edc6e812b342f6ad.
    [2023-06-14.CSV, 2023-06-15.CSV, 2023-06-16.CSV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]
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2023-07-18 Reorganizing of folders in repo
    Everything related to Loadcell is in Loadcell folder
    [2023-06-14.CSV, 2023-06-15.CSV, 2023-06-16.CSV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]
2023-07-19 Applying F() macro on strings/syntax corrections
    To avoid stocking strings in variables memory, the F() can be used to save on sketch memory. The variables was full without this step when compiling.
    [Loadcell.cpp, Loadcell_controller.cpp]
2023-07-21 Adapt drift sketch to libraries newest version
    [Loadcell.cpp]
2023-08-16 Add doxygen documentation and comment
    The two libraries were documented with doxygen formated docstrings. A few functions were added to LoadCellController class to access a LoadCell completely through the LoadCellController
    [Bottle holder v1.stl, base loadcell v1.stl]
2023-08-18 Modification CAD .stl files
    [Bottle holder v1.stl, base loadcell v1 v4.stl, plateforme loadcell v1 v8.stl]
2023-08-20 File name change
    [2023-06-14.CSV, 2023-06-15.CSV, 2023-06-16.CSV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]
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2023-10-04 Code adapted to SPIFFS ESP32
    The functions related to eeprom on the arduino have been changed to more general function that can handle SPIFFS of a ESP32 board. Not done
2023-10-11 SPIFFS saving and reading works
    The SPIFFS implementation for the saving/reading of the calibration parameters now works for the esp32 firebeetle.
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2023-11-24 Add sketch examples
    Modify the mode switching sketch to make it work with SD card. Adding a file with functions which can manage the file on the SD card and read them.
2023-12-10 Linear test
    Adding the data, python code for graph and the firebeetle sketch for the linearity test of a 100g load cell.
    [testlinearityloadcelldata.csv]
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2023-12-20 Test of a 300g load cell with 200g
    Arduino sketch for the experiment, the csv data file and the python code to produce a simple graph.
    [300gLoadCellWithWheelGraphData.csv]
2024-01-12 Update TestLoadCellandHX711.ino
    Changing the pins for clock pin on the pcb version 1.
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2024-02-14 Create 20240214_outliersfiltering.py
    First version of outliers filtering on weight data with python
2024-03-20 Add new raw weight data with mouse (2024.02.14)
    [20240214-FirstTEstWithMouseAfterChangedWithPCBNoAverageRAWdata.csv]
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2024-04-15 20240415-AutreMiniModifParRapportAuPlot
    J'ai aussi fait la somme des données des 3 balances dans firsttest.py
2024-04-16 2024.04.15 : Ajout d'un seuil pour les outliers négatifs qui est différent du seuil pour les outliers positifs
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2024-05-14 adding outliers filtering on Cage data
    not working yet
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2024-05-30 Smooth mean weight change over time and correct for boundary effects from convolution
    - convolution_filter() is now convolution)filter_with_egde_padding(). The boundary effect from the convolution filtering is corrected with edge padding.
    - added the function "reset_data()" to reset the data to the raw data after a certain task is completed.
    - the function compute_mean_data() produces a smooth weight change over time. The level of smoothness can be adapted with the variable smooth_level.
    -
2024-06-04 Moved folders to make it more manageable and to keep traceability.
    We should always modify the same file rather than creating new ones for every test.
2024-06-06 added reconnection to wifi after an hour to make sure the device stays connected. Commented out most of the serial prints to get faster acquisition
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2024-06-13 Hanging events are identified correctly
    1. Remove outliers (outliers = points that are very different from their neighbours)
    2. Convolve with a small window (15 points) to smoothen the data
    3. High-pass filter in convolution. Identifies moments when the weight data changes drastically.
    4. I use conditions to verify where are the hanging events according to the number of points between the start index and the end index. For example, if the number of points between start and end is under 5 points (which is under 1 second), do not consider this as a hanging event. So I set a minimal hanging time of 1 second. Also, is end-start > 900 points, so 3 minutes, do not consider this as a hanging event.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
2024-06-22 Small corrections + test new measurements from pcb version 2
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2024-09-03 Added kicad files for pcb v2
    [20240611-SMARTCAGE-PCB-V2-B_Cu.gbr, 20240611-SMARTCAGE-PCB-V2-B_Mask.gbr, 20240611-SMARTCAGE-PCB-V2-B_Paste.gbr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]
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2024-10-10 Location is identified and evaluated compared to ground truth from video
    The location of the mouse is identified correctly with the weight data from individual time series of each scale. The total error and precision is computed as well with a different class method.
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2024-12-19 PCB files for multiple clocks, using pin 4 for load cell 1, pin 16 for 2 and 17 for the third.
    [2024-12-19-3-Clocks-B_Cu.gbr, 2024-12-19-3-Clocks-B_Mask.gbr, 2024-12-19-3-Clocks-B_Paste.gbr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]
2025-02-17 Faire version 3 de PCB
    Avec polygone aux deux layers.
    Avec une clock par controllers.
    [2024-12-19-3-Clocks-B_Cu.gbr, 2024-12-19-3-Clocks-B_Mask.gbr, 2024-12-19-3-Clocks-B_Paste.gbr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]
2025-09-23 Add CADs for CSDS scales
    [20231115-PlaquetteDeBalanceBottomLeftEnBol-Version1.step, 20250217-TestRight v1.step, 20250217-TestRight v2.step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]
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2025-11-08 J'ai essayé de STFT de scipy avec un hmm pour cluster les comportements.
    n_states Adjusted random index Normalized mutual information score Fowlkes-Mallows Index
    2 -0.0278 0.03372 0.6149
    3 -0.0144 0.1301 0.4437
    4 0.1338 0.2071 0.4915
    5 0.0547 0.1831 0.3957
    L'interpolation des données de poids avant de faire le STFT semble tout briser donc je l'ai pas utilisé, ce qui veut dire que quand la STFT passe sur mes données, parce que la window est fixe, ça va pas toujours prendre le même temps. En effet, mon sampling frequency n'est pas stable dans le temps, ça varie de genre 1 HZ à 43 Hz. Je dois fixer ça je pense et ça va m'aider. pour faire la STFT.
2025-12-09 Test identifying grooming-like behaviour
    [data.csv, on_scale.csv, targets.csv]
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2026-03-13 Version 5 of main.py
    [2026.01.23-TestFirstPCBWith3Scales.csv, data.csv, on_scale.csv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]
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2026-05-06 Reject HX711 raw == -1 as corrupted (workaround for GPIO 9/flash conflict)
    The HX711 returns 0xFFFFFF (-1 after sign extension) when DOUT is held
    HIGH during the read, e.g. when the chip enters power-down mid-read or
    when DOUT shares a pin with the flash SPI bus (GPIO 6-11 on ESP32).
    On the current STUAART boards, cell 1 DOUT is on GPIO 9 which is
    physically wired to the external flash on ESP32-D0WD modules; ~98% of
    the outliers in cell 1 data are exactly this signature.
    Add safe_read() that retries up to 3 times on raw == -1, and have the
    three averaging functions exclude such samples from the average rather
    than including them. Returns -1L when all retries fail; callers should
    treat -1L a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
2026-05-06 Initialize SD card once in setup, gate writes on success
    createFile() was calling SD.begin() on every invocation, which
    re-initialised the card every time saveData() ran with a missing
    today's-file. With no SD inserted on the bench, this printed
    "initialization failed!" on every loop iteration and slowed the
    sketch to ~1 Hz.
    Move SD.begin() into setup() and track success in a global
    sdInitialized flag. createFile() and saveData() now skip SD
    operations cleanly when no card is present, so the sketch keeps
    streaming readings on Serial without spam.
    [STUAART.ino]
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2026-05-06 Drop ArduinoLibraries/, move PDF to Firmware/docs/, document Loadcell/
    Loadcell/ArduinoLibraries/ no longer made sense after the libs moved
    to Firmware/STUAART/. Move the API documentation PDF to
    Firmware/docs/LoadCell-API-V2.02.pdf and delete the Doxyfile
    (referenced now-stale paths; regenerate from Firmware/STUAART/ when
    newer docs are needed).
    Add Loadcell/README.md so a fresh visitor understands the role of
    each subfolder (drift tests, linearity, mouse experiments, example
    sketches, outlier filtering script) and knows where the production
    firmware actually lives.
2026-05-06 Rewrite top-level README around the new Firmware/ layout
    The previous README pointed readers at Loadcell/ArduinoLibraries/ for
    libraries, instructed them to copy folders into Arduino's libraries
    directory, and contained a broken "soleil_controller" code example.
    None of those steps are correct anymore.
    New README:
    - Concise repository tour pointing at Firmware/ as the entry point
    - Three-step install via Library Manager (HX711, RTClib, ArduinoJson)
    and arduino-cli/Arduino IDE 2.x build instructions
    - Working minimal-read code example
    - Documents the GPIO 9 / flash-bus conflict on PCB V2 (cell 1 DOUT)
    and the strap-to-D2/D3 mechanical workaround
    - Keeps the troubleshooting tips (CH340 92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
2026-05-06 Add 'set offset <n> <v>' and 'set scale <n> <v>' serial commands
    Manual setters for the calibration constants, complementing the
    measurement-based 'tare' and 'cal' commands. Useful when the value is
    known from another card or a previous calibration session and one
    wants to impose it directly without re-measuring (e.g. when the
    in-place tare is corrupted by the GPIO 9 / flash issue on cell 1).
    No y/n confirmation : the value is explicit, and the command does not
    depend on the physical state at the moment of execution (unlike
    'tare' or 'reset').
    [STUAART.ino]
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2026-05-06 Capture improvements from CageServer/FireBeetleServer parallel rewrite
    Daniel maintained a parallel rewrite of the STUAART firmware in
    CageServer/Code/FireBeetleServer/ on the improved-documentation
    branch. It was never deployed but contains a few good ideas worth
    porting into Firmware/STUAART/STUAART.ino when there is time :
    - RTC time-keeping fallback to millis()/1000 if getLocalTime() fails
    - HX711 initialize() + is_responding flag to detect dead cells at boot
    - ArduinoLog-based logging (Log.errorln, Log.noticeln, ...)
    - assert() macro for parameter validation (drops ~400 lines of error
    printing)
    - add_loadcell(dout, sck, gain) overload that constructs the cell
    internally
    Each patte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
2026-05-06 Improve Doxygen docs : new mainpage, fix 15 warnings to zero
    LoadCell.h mainpage was a 4-line placeholder. Replace it with a real
    overview that documents :
    - what each class does
    - minimal usage example
    - the three HX711 corruption signatures (0xFFFFFF, 0x800000, 0x7FFFFF)
    and how safe_read() handles them
    - the GPIO 9 hardware caveat the software cannot fully fix
    - pointers to bogde/HX711 and the STUAART repo
    Repair all 15 source-code warnings flagged by Doxygen :
    - Replace unresolvable @ref to protected members and to non-existent
    methods with backticked plain text (or the real existing name :
    calibrate_offset() -> calibrate_tare_offset(),
    easy_get_weight_with_auto_recalibration()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
    [LoadCellController.h]
2026-05-06 Trim Doxygen PDF from 62 to 39 pages by suppressing empty chapters
    For a project with 2 classes, several Doxygen chapters were
    near-empty filler that just duplicated the table of contents :
    - Topic Index / Topic Documentation (no @defgroup used)
    - alphabetical Class Index
    - File Index / File Documentation (duplicates the class docs)
    Configure the Doxyfile to suppress these and to skip verbatim source
    listings (the actual code lives in the repo, no value in re-printing
    it). Also turn on COMPACT_LATEX and SHOW_USED_FILES = NO for a tighter
    layout.
    Replace three Unicode 'in' set-membership symbols (U+2208) with the
    ASCII word 'in' so pdflatex builds without Unicode font errors.
    Result : 39 p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
2026-05-06 Document the serial command interface in Doxygen
    Add a dedicated @page (STUAART Serial Command Interface) with :
    - behaviour overview (115200 baud, non-blocking, line-echoed)
    - y/n confirmation flow for destructive commands
    - full command reference table (16 commands, what they do, whether
    they ask confirmation)
    - typical bench workflows (tare + cal + save, live streaming, manual
    set + save)
    - implementation notes pointing at the dispatch and accumulation
    functions
    - persistence note (set offset / set scale modify only RAM, save
    pushes to SPIFFS, auto-mode tare overwrites offset on reboot)
    Add @brief Doxygen comments to each command-handling function :
    printHelp, printInfo, readOnce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
    [STUAART.ino]
2026-05-06 Convert all STUAART.ino comments to Doxygen format
    Every function in the sketch now has a /** @brief ... */ block:
    WiFi / network :
    - connectToWifi : timeout behaviour, post-success setup, called from
    loop() too for hourly retry
    - getTimeHTTP : marked as a stub (the JSON parse is wired but the RTC
    push is commented out)
    RTC :
    - startRealTimeClock : compile-time fallback, halt-on-failure
    - getTodaysDate / getYesterdaysDate : note that getYesterdaysDate
    fails on the first of any month
    SD I/O :
    - writeFile : explains the RAM ring buffer + flush-on-full strategy
    - createFile : single-line write, no-op when sdInitialized is false
    - addToBuffer : ring increment + bufferFull semantic
    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
    [STUAART.ino]
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2026-05-07 Per-cell HX711 read statistics : `stats` and `reset stats` commands
    Add four lifetime counters to each LoadCell instance :
    - total_reads : every HX711 conversion consumed by safe_read
    (initial reads + retries)
    - corrupted_neg1 : count of 0xFFFFFF (-1L) signatures observed
    - corrupted_negsat : count of 0x800000 (-8388608L) signatures
    - corrupted_possat : count of 0x7FFFFF (+8388607L) signatures
    Plus :
    - total_corrupted() : sum of the three corruption counters
    - reset_stats() : zero all four counters
    safe_read() increments total_reads on every read() call and the matching
    corrupted_* counter every time a corruption signature is observed (initial
    re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
    [STUAART.ino]
2026-05-07 Document the new stats counters and the stats / reset stats commands
    - Add stats and reset stats to the command reference table on the
    serial_commands @page in STUAART.ino
    - Add a Live corruption statistics section to corruption.dox listing
    the four counters, showing example stats output, and explaining the
    before / after strap use case
    - Regenerate the PDF (52 pages, 0 Doxygen warnings)
    The four LoadCell counters (total_reads, corrupted_neg1,
    corrupted_negsat, corrupted_possat) are already documented inline in
    LoadCell.h via @brief blocks, so they appear automatically in the
    class reference section of the PDF.
    [STUAART.ino]
2026-05-07 Remove duplicate corruption section from the mainpage
    The HX711 corruption section in LoadCell.h's @mainpage was a condensed
    version of what now lives on the dedicated @ref corruption page. With
    the page in place, the mainpage version is out of context and noisy.
    Replace it with a short Further reading section that lists the four
    dedicated pages (architecture, corruption, calibration, serial_commands)
    as cross-references, so the mainpage stays a true overview.
2026-05-07 Host-side unit tests + fix three real warnings (#50)
    * Host-side unit tests for the LoadCell class
    POC for host (native) testing of the firmware logic without flashing
    an Arduino. The production sketch in Firmware/STUAART/ is unchanged ;
    tests live entirely in test/native/.
    Approach :
    - Stubs in test/native/stubs/ replace Arduino.h, HX711.h, SPI.h for the
    test build only. The mock HX711 provides a programmable mock_sequence
    that scripts the next return value of read() ; tests push values and
    verify that LoadCell::safe_read retries the right number of times,
    that the averaging methods exclude corrupted samples, and that the
    lifetime counters increment as expected.
    - The Makefile c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
    [LoadCellController.cpp, LoadCellController.h]
2026-05-07 Runtime WiFi credential change : `wifi set` and `wifi show` commands (#51)
    WiFi SSID / password are no longer hardcoded `const char*`. They are
    char buffers populated at boot from /wifi.txt on SPIFFS (with the
    compiled-in defaults as fallback) and can be changed at runtime via
    two new serial commands :
    wifi show
    Show current SSID. The password is NEVER printed (only its length
    is reported), to avoid leaking it to anyone with access to the
    bench Serial port.
    wifi set <ssid> <password>
    Update the credentials in RAM, persist them to /wifi.txt on
    SPIFFS, and call connectToWifi() to reconnect with the new
    settings. Limitations : sscanf %s parsing means neither SSID n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
    [STUAART.ino]
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2026-05-08 Show web server URL in info command (#53)
    * Show web server status in `info` output
    Adds a `Web srv :` line to printInfo with three possible states :
    Web srv : running at http://192.168.1.42/ (WiFi up + server.begin done)
    Web srv : started but WiFi is down (WiFi dropped after first connect)
    Web srv : not started (WiFi never came up since boot)
    Backed by a new `webServerStarted` global, set to true once
    server.begin() succeeds inside connectToWifi. Useful when probing the
    HTTP server externally fails : the user can compare the IP reported
    by `info` against the one they were trying to reach (DHCP may have
    moved it after a reboot).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
    [STUAART.ino]
2026-05-26 Add ai/: mouse load-cell action-recognition pipeline + report
    Imports the action-recognition-mice-with-load-cells project into ai/:
    end-to-end L1–L8 cleaning pipeline (parse → clock → channel-clean →
    tare/fuse → off-scale gate → 80 Hz resample → label sync → windowing),
    six model-family modelling study, and the full REPORT.md / SUMMARY.md
    documenting the ~0.60 within-session 3-class accuracy ceiling.
    [2025.11.17-RawMassTimeSeries-NoBufferFlushes.csv, 20251117-GroundTruthAfterWatchingVideo.xls]
2026-05-27 Add Mouse3 active-vs-sleeping classification
    New study on the Mouse3-3heures-10Hz recording: whole-recording sleep/wake
    scoring from m_total alone. Opposite regime to the dataset-1 gesture ceiling
    (0.60-0.65) — active vs sleeping is near-trivial.
    - src/mousepipe/mouse3.py: 25 Hz config, sync derivation (mouse-in load step),
    CSV H:MM:SS label parser, sleep/active rasterize, segment-aware windower,
    movement index. Reuses dataset-1 L1-L5 unchanged.
    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
    [2025.10.28-RawWeightData-80Hz.csv, Eating-Table 1.csv, General info-Table 1.csv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]
2026-10-08 Delete all unecessary files
    All files were stored in my personal drive before being removed from GitHub
    [2023-06-14.CSV, 2023-06-15.CSV, 2023-06-16.CSV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]
2026-10-08 Add CADs for platform 3D printing
    [BottomLeft.step, BottomMiddle.step, BottomRight.step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]
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
